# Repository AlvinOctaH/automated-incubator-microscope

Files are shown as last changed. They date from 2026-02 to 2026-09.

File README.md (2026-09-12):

# 🔬 Automated Incubator Microscope

<div align="center">





**A custom 3-axis automated microscope stage for continuous long-term live-cell imaging, developed at NCKU.**

[Overview](#overview) · [Mechanical](#-mechanical) · [Electrical](#-electrical) · [Software](#-software)

</div>

---

## Overview

An automated XYZ microscope stage designed for continuous 24/7 brightfield imaging of biological samples (spheroids) in wellplates. Built around a Raspberry Pi 4 and Arduino Nano V3, the system enables unattended long-term live-cell imaging with motorized focus and sample positioning.

<p align="center">
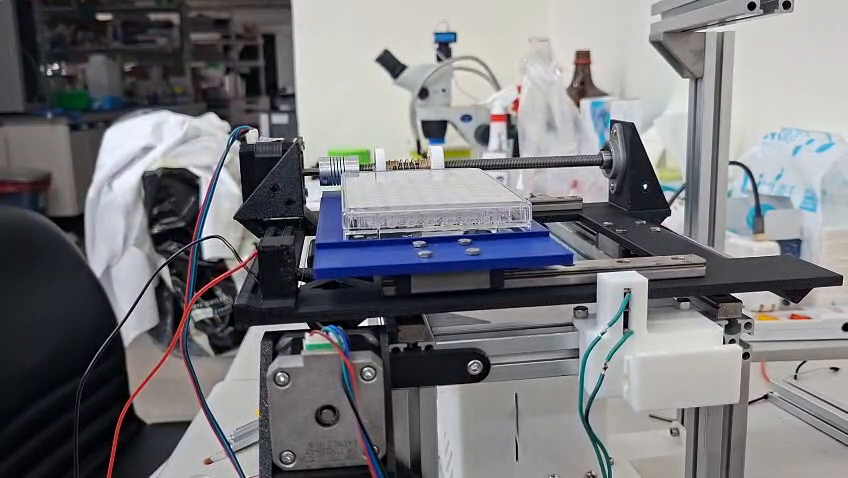
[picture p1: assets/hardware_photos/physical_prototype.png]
  
  <br/><sub>The assembled prototype — wellplate stage, lead screws, and objective column.</sub>
</p>

| Feature | Specification |
| :--- | :--- |
| Axes | X, Y, Z (independent translational) |
| Linear Resolution | 5 µm/step (full-step) |
| Travel (Z) | ~15 mm |
| Motor Driver | DRV8825 |
| Controller | Arduino Nano V3 + Raspberry Pi 4 |
| Camera | Raspberry Pi HQ Camera (IMX477) |
| Target Sample | 96-well plate |
| Primary Material | PLA-CF |
| Operating Mode | Continuous 24/7 |

**Objectives**

- Develop a 3-axis (XYZ) automated microscope stage capable of functioning reliably inside a standard cell culture incubator.
- Enable automated brightfield imaging across all 96 wells in serpentine order with minimal user intervention.
- Minimize contamination risk and preserve spheroid sample integrity throughout continuous long-term experiments.

---

## Related Work

A few existing projects tackle automated or incubator-compatible microscopy:

- Baudin et al., 2021 — [Low cost cloud based remote microscopy for biological sciences](https://doi.org/10.48550/arXiv.2106.07419) (the "Picroscope," a cloud-controlled remote imaging platform for cell culture plates)
- Burke et al., 2024 — [EnderScope: A Low-Cost 3D-Printer-Based Scanning Microscope](https://doi.org/10.1098/rsta.2023.0214)
- Dégut & Plevin, 2025 — [An open-sourced 3D printable microscope with a large CNC stage](https://doi.org/10.3390/mi13060833)
- Gervasi et al., 2022 — [Automated Open-Hardware Multiwell Imaging Station for Microorganisms Observation](https://doi.org/10.1101/2024.12.31.630915)
- Merces et al., 2021 — [The incubot: A 3D printer-based microscope for long-term live cell imaging within a tissue culture incubator](https://doi.org/10.1016/j.ohx.2021.e00189)

This project's own angle: a stage sized and optically configured specifically for a standard 96-well plate, with a quantified per-axis repeatability test (not just a claim that it's repeatable) and a web-based experiment runner built for unattended multi-day scans.

---

## 🔩 Mechanical

### 1. Components & Specs
| Component | Specification | Quantity |
| :--- | :--- | :---: |
| Stepper Motor | NEMA17 42-40, 1.8°/step, ~40 N·cm holding torque | 3 |
| Lead Screw | T8, 1 mm pitch | 3 |
| Anti-backlash Nut | 8 mm | 3 |
| Flexible Coupler | 5 mm to 8 mm | 3 |
| Linear Rail | MGN12H | 3 |
| Aluminum Extrusion | Alpro, various lengths | — |

#### Enclosure (design only — not yet fabricated)

<p align="center">
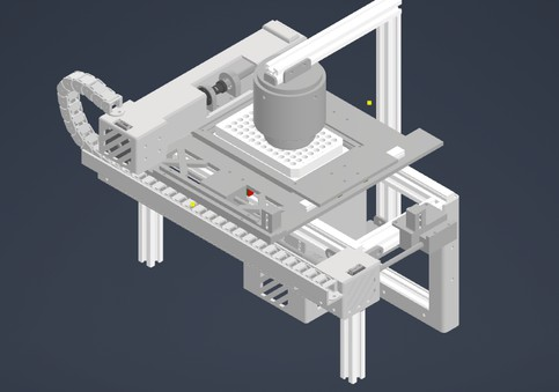
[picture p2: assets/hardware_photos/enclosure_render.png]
  
</p>

> This protective enclosure has been designed in CAD but not yet 3D-printed or fitted to the prototype — it's not part of the assembled hardware shown elsewhere in this README.

### 2. Motion Calculation

#### Degrees of Freedom (DOF)

<p align="center">
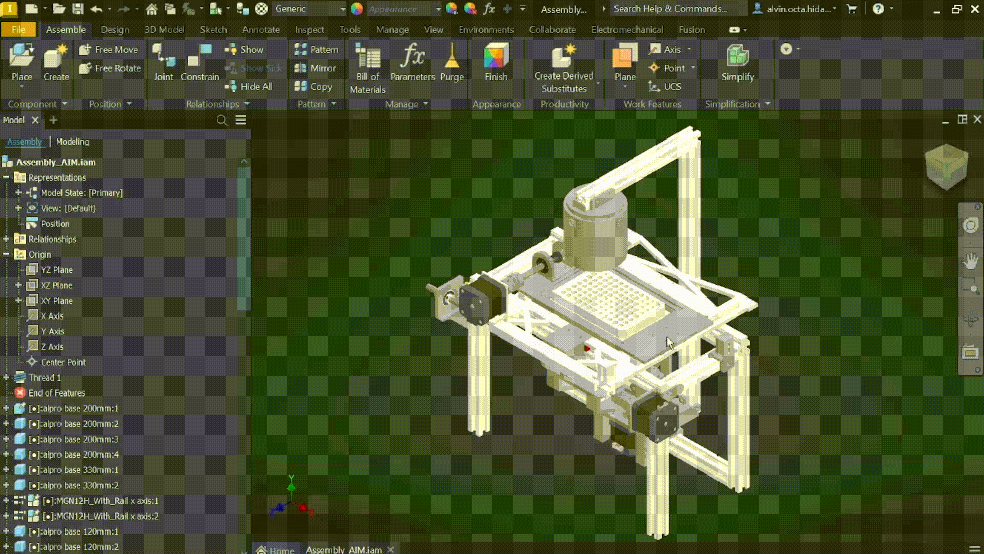
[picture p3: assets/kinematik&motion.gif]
  
</p>

Each axis provides exactly 1 translational DOF with no unintended rotational or parasitic motion, confirming proper constraint and assembly.

| Axis | DOF Type | Notes |
| :--- | :--- | :--- |
| X | 1 Translational | Stacked system |
| Y | 1 Translational | — |
| Z | 1 Translational | Focus axis |

#### Lead Screw Motion

- **Lead screw pitch:** 1 mm/rev  
- **Stepper motor:** 200 steps/rev, full-step (all axes)

**Theoretical linear resolution:**

$$
\text{Resolution} = \frac{\text{Lead Screw Pitch}}{\text{Steps per Revolution}} = \frac{1\ \text{mm}}{200 \times 1} = 0.005\ \text{mm} = 5\ \mu\text{m}
$$

**Required steps for full Z travel (9 mm gap between plates):**

$$
\text{Required Steps} = \frac{9\ \text{mm}}{5\ \mu\text{m}} = \frac{9000\ \mu\text{m}}{5\ \mu\text{m}} = 1800\ \text{steps}
$$

#### Interference Analysis

<p align="center">
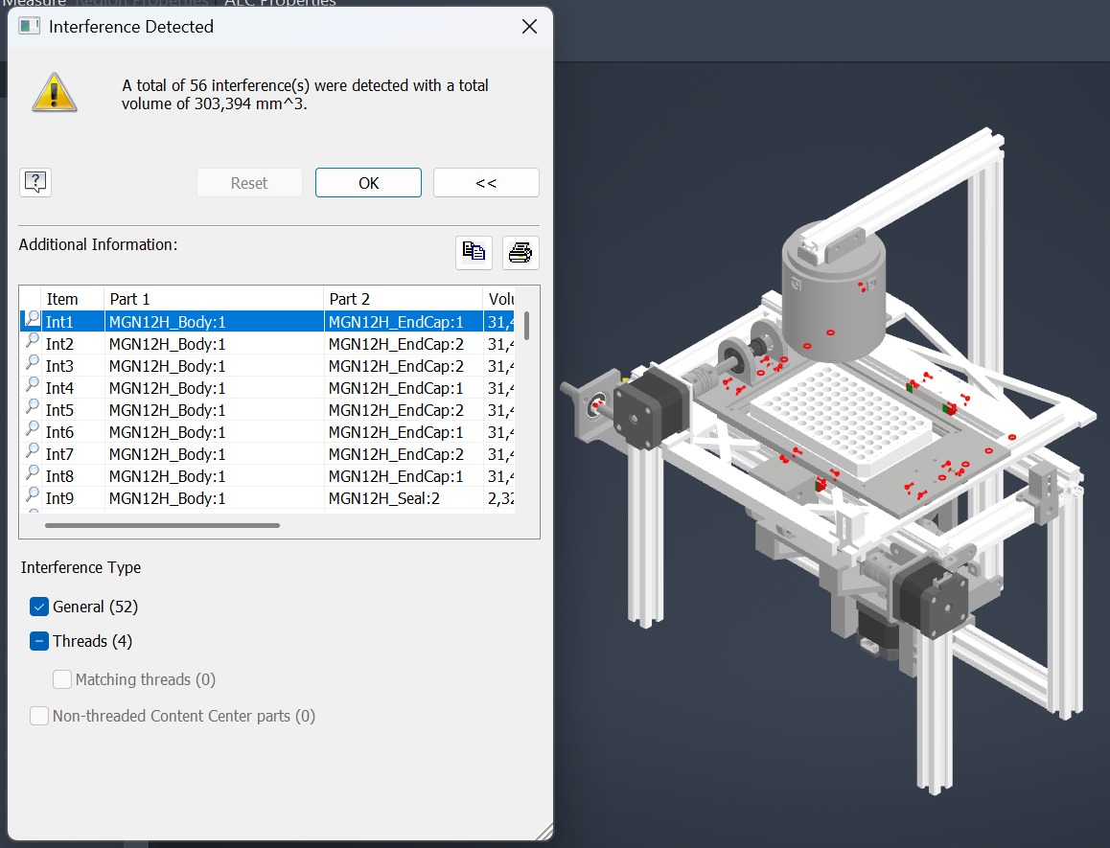
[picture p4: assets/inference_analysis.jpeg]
  
</p>

> ⚠️ **Note:** The interference analysis flags several overlaps in the CAD model. These occur within intentionally modeled precision components (linear rails, KFL08 bearing threaded regions) and are not physically relevant in real-world assembly. No functional collisions exist in the final design.

---

### 3. Material Comparison

Static load analysis was performed on the stage plate under gravity only
(−Z, 9.81 m/s²). Three materials were evaluated: **PLA-CF**, **PLA-Basic**,
and **Aluminum 6061**.

**Displacement** shows how much the structure physically deforms under load —
lower values indicate a stiffer, more stable platform, which is critical for
maintaining focus consistency during imaging.

**Von Mises Stress** shows the internal stress distribution across the
structure. Results dominated by blue contour across all three materials
indicate that stress levels remain well within safe limits throughout the
structural body under gravity-only loading.

**Safety Factor** is derived from the ratio of material yield strength to
local von Mises stress. Values above 2 are generally considered acceptable
in engineering practice. The minimum value is read from the Inventor SF
contour plot — peak stress occurs only at localized concentration points,
while the majority of the structure maintains a high safety margin as
confirmed by the blue-dominated contour.

> ⚠️ Note: Peak displacement values include contribution from motor assembly
> motion. Structural frame comparison is best assessed from the color contour
> distribution in the images above.

#### Material Properties

| Property | PLA-CF | PLA-Basic | Aluminum 6061 |
| :--- | :---: | :---: | :---: |
| Young Modulus (MPa) | 2790 | 2750 | Default Autodesk Inventor |
| Poisson Ratio | 0.33 | 0.36 | Default Autodesk Inventor |
| Shear Modulus (MPa) | 1048 | 1010 | Default Autodesk Inventor |
| Yield Strength (MPa) | 38 | 35 | Default Autodesk Inventor |

#### A. PLA-CF

<details>
<summary>Displacement</summary>
<p align="center">
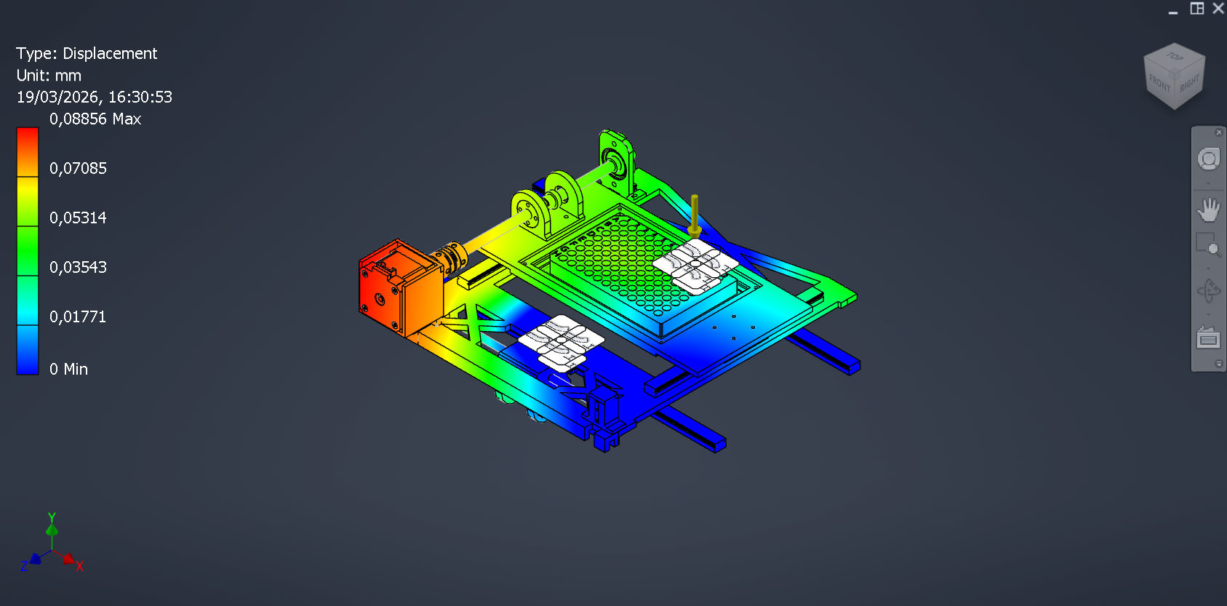
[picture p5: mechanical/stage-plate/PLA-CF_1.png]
  
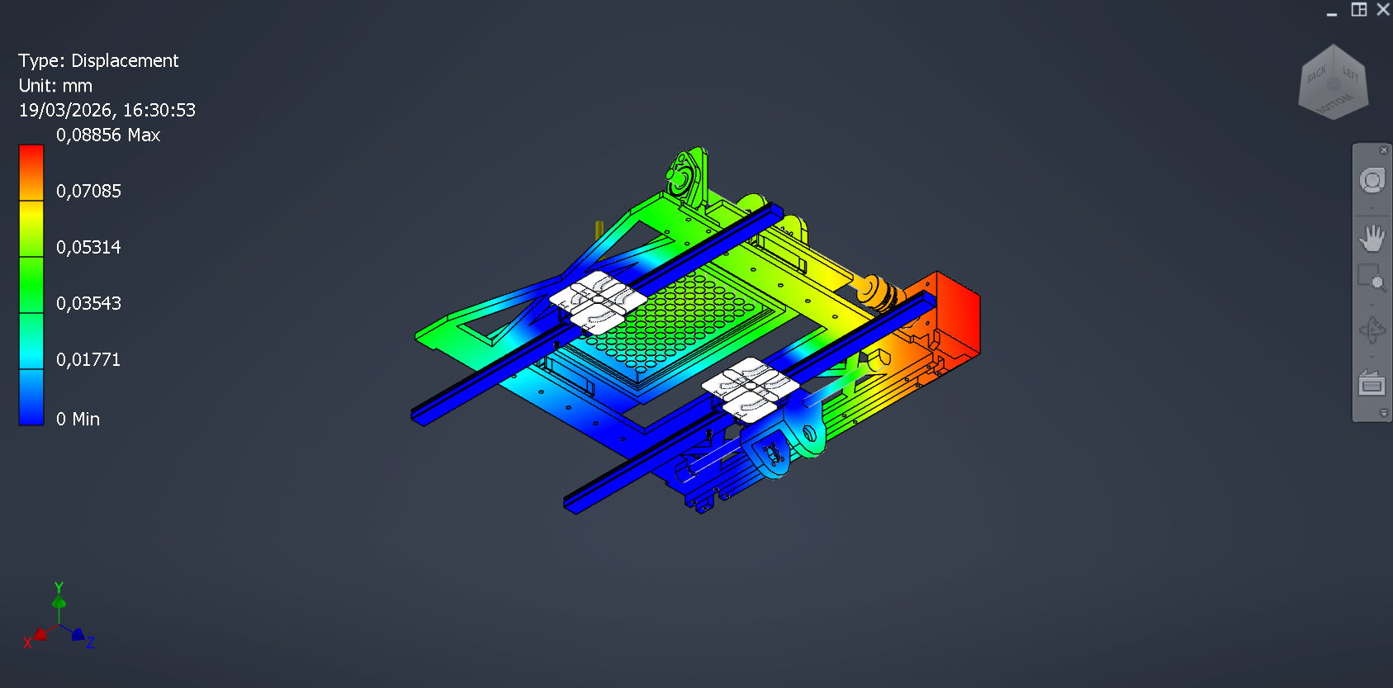
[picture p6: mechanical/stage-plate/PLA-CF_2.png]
  
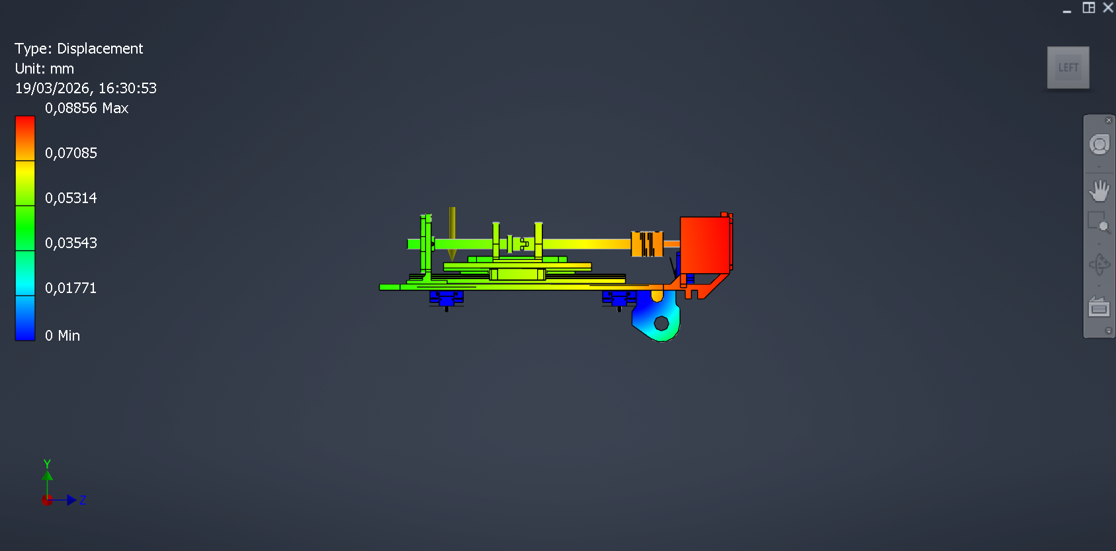
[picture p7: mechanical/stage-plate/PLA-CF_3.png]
  
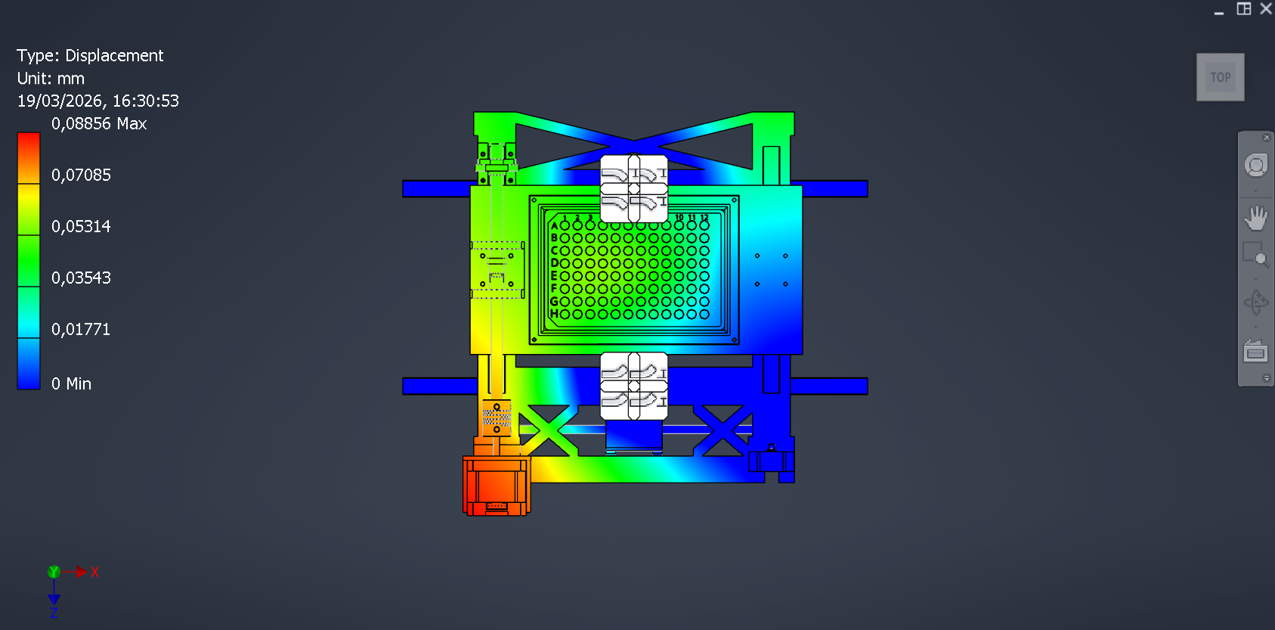
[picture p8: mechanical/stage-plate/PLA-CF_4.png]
  
</p>
</details>

<details>
<summary>Von Mises Stress</summary>
<p align="center">
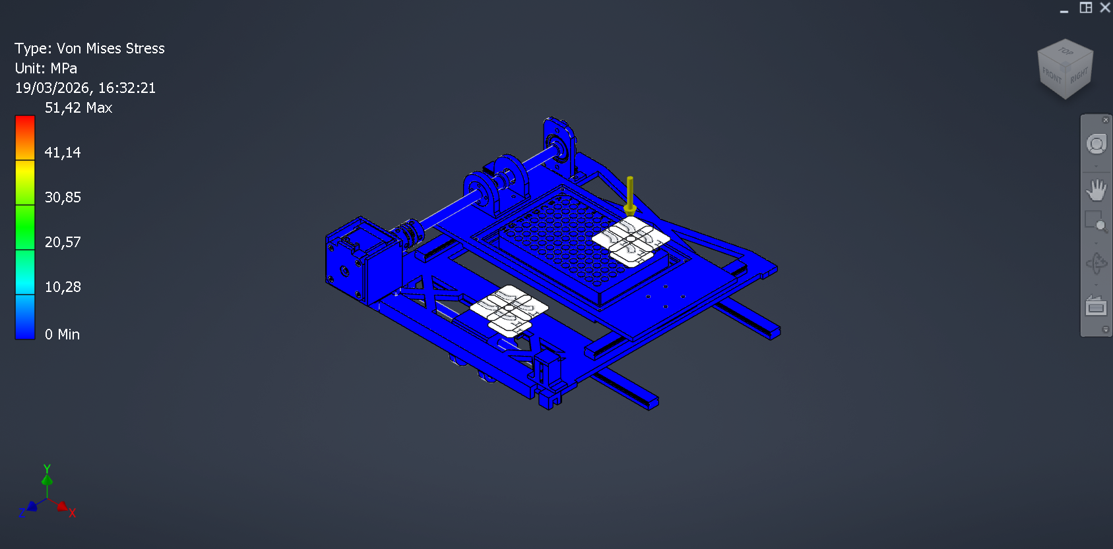
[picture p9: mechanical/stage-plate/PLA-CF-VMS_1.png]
  
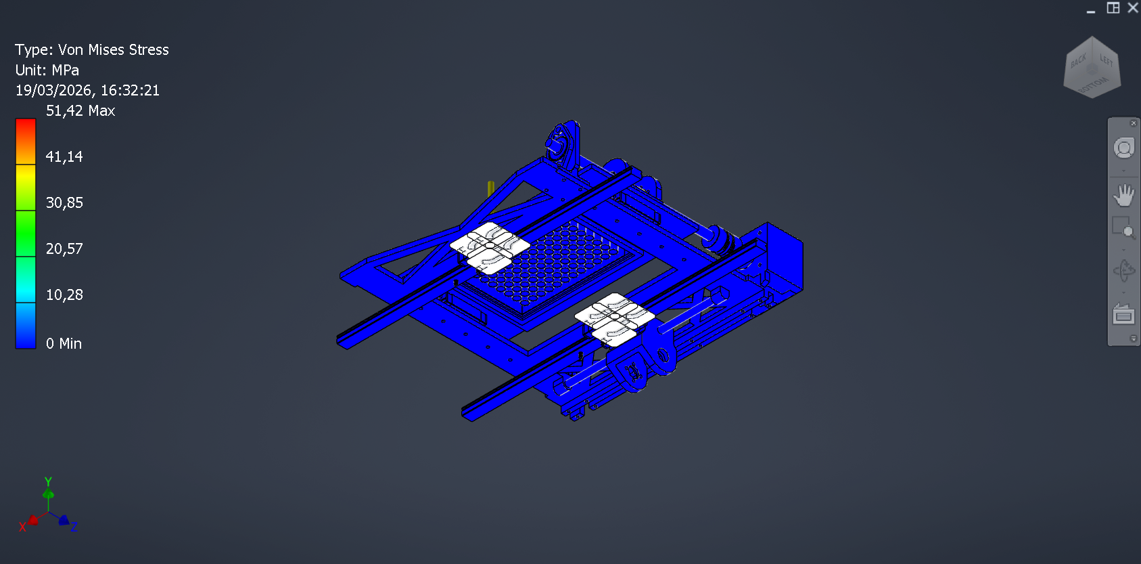
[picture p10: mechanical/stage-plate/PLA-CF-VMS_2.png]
  
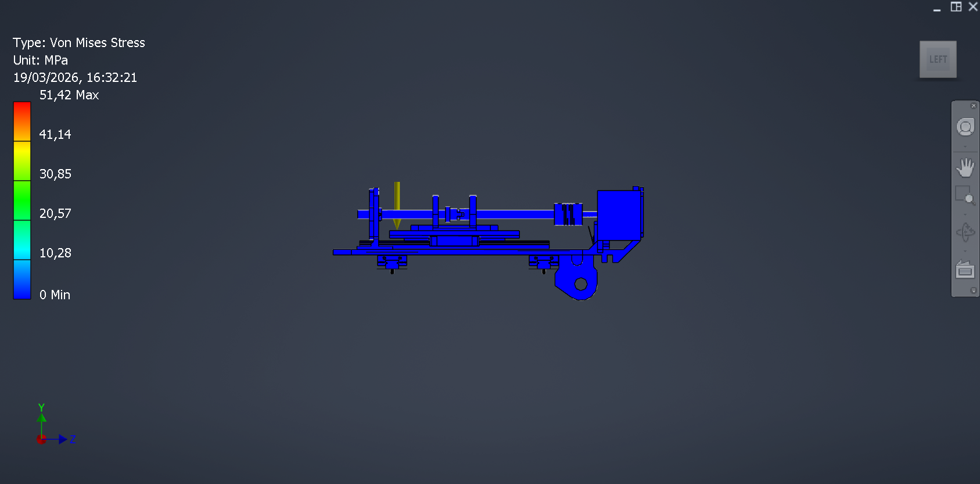
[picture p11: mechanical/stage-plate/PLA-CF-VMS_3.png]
  
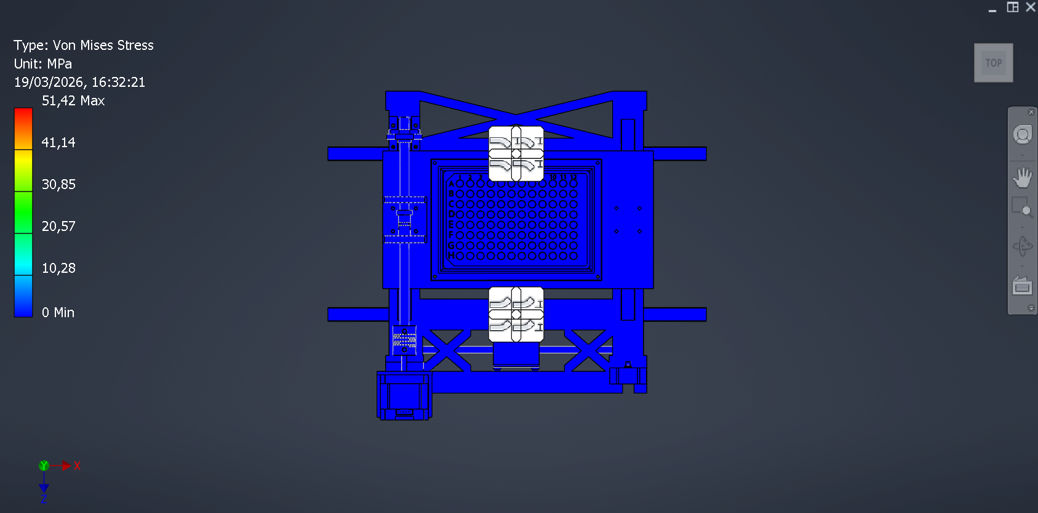
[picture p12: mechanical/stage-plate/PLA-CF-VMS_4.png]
  
</p>
</details>

<details>
<summary>Safety Factor</summary>
<p align="center">
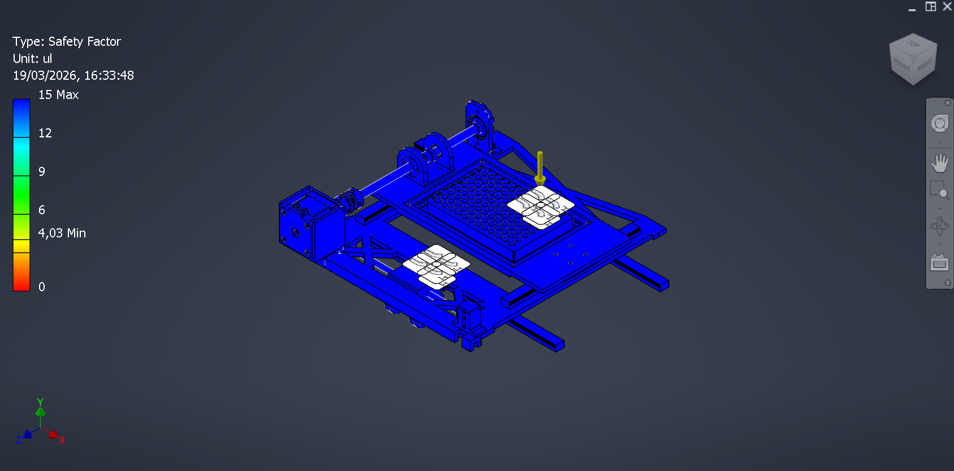
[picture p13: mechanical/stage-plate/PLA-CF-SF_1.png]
  
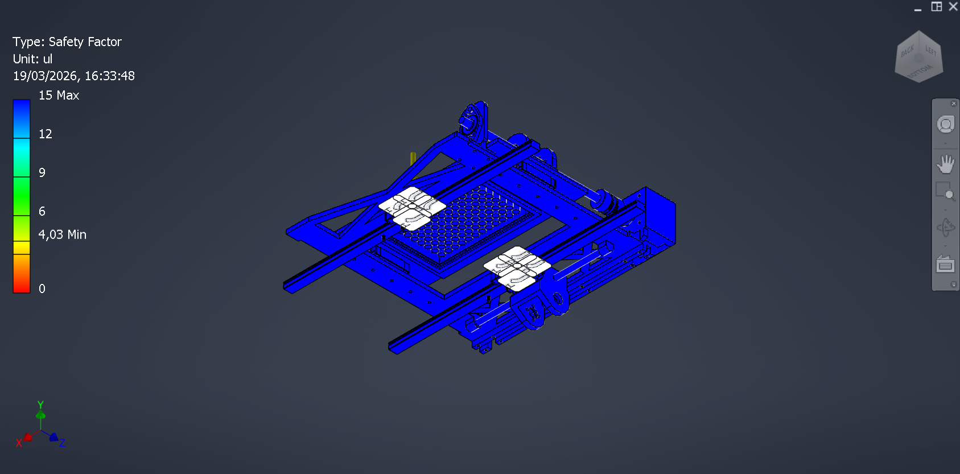
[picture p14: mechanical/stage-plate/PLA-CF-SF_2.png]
  
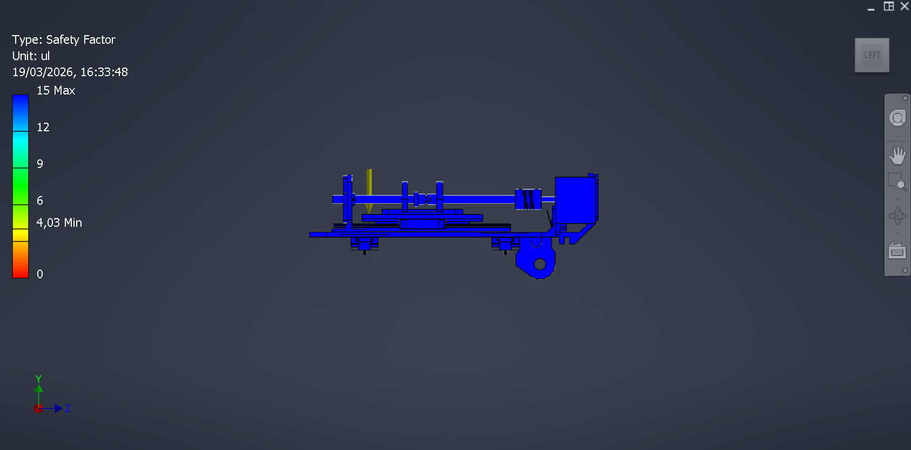
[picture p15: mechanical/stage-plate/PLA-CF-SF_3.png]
  
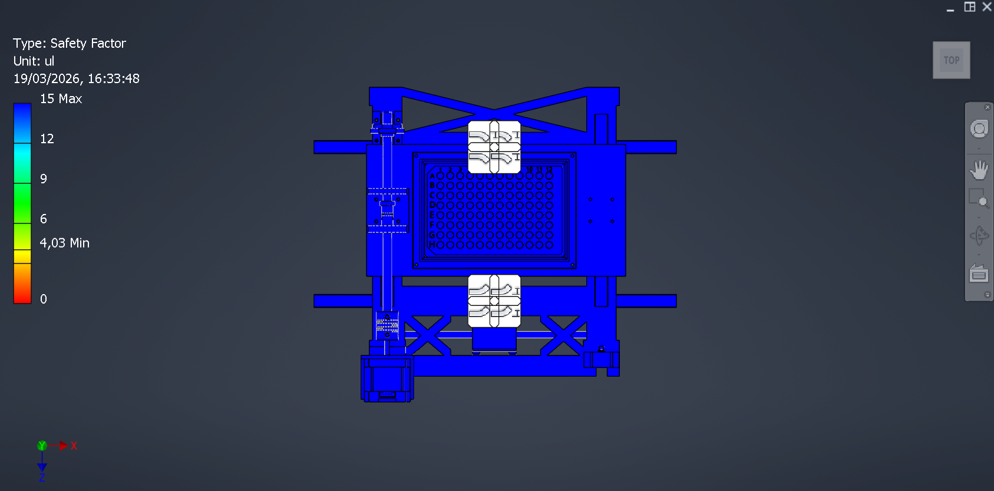
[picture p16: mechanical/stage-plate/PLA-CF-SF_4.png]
  
</p>
</details>

- Max displacement: **0.089 mm**
- Max von Mises stress: **51.42 MPa** — stress distribution dominated by blue contour, structure is safe throughout
- Min safety factor: **4.03** — well above acceptable threshold
- Carbon fiber reinforcement improves stiffness compared to PLA-Basic

#### B. PLA-Basic

<details>
<summary>Displacement</summary>
<p align="center">
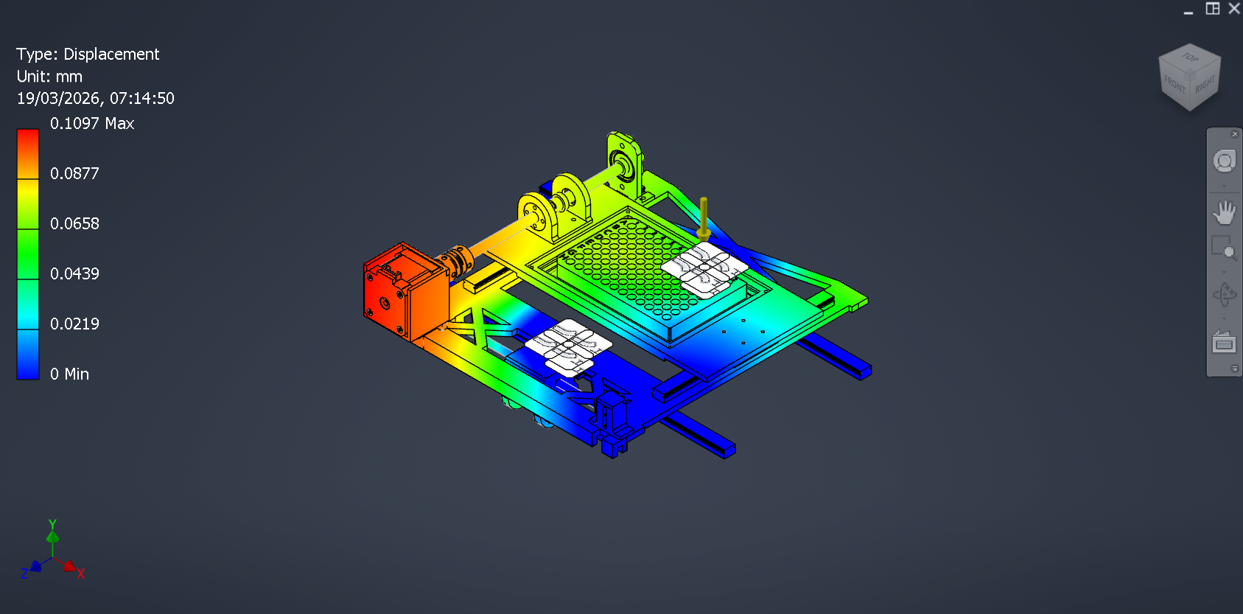
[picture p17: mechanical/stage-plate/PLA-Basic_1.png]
  
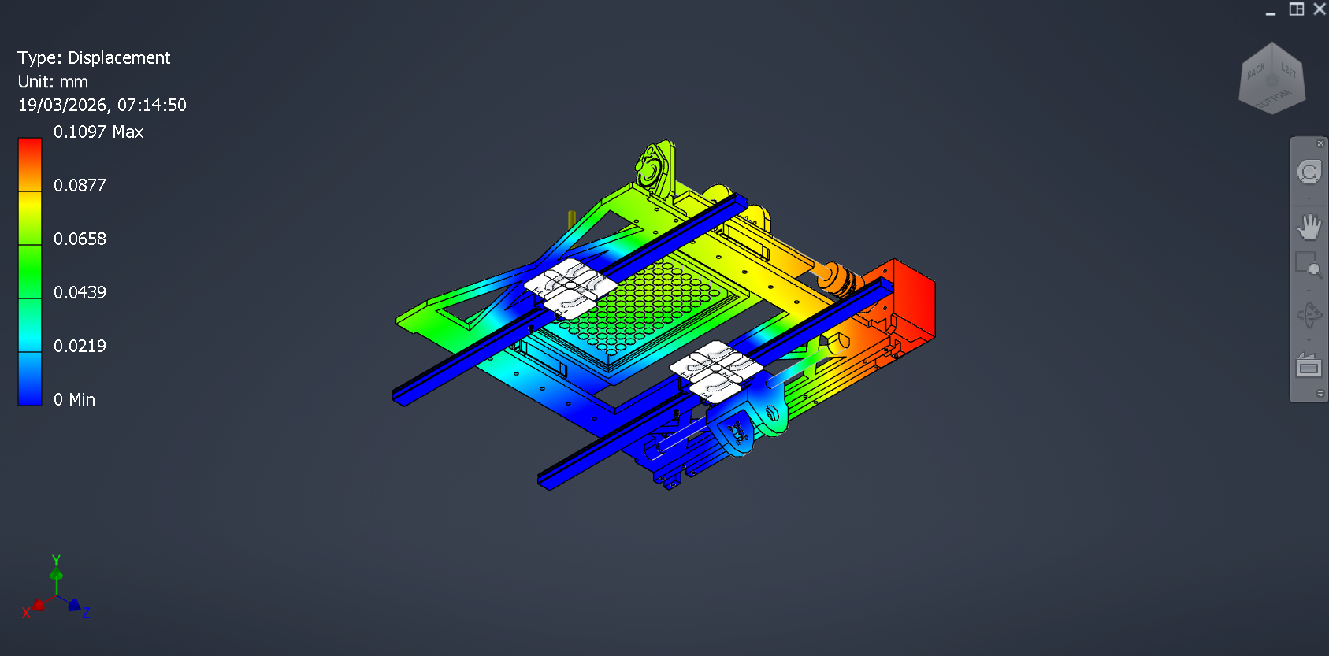
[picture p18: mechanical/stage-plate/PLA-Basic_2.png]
  
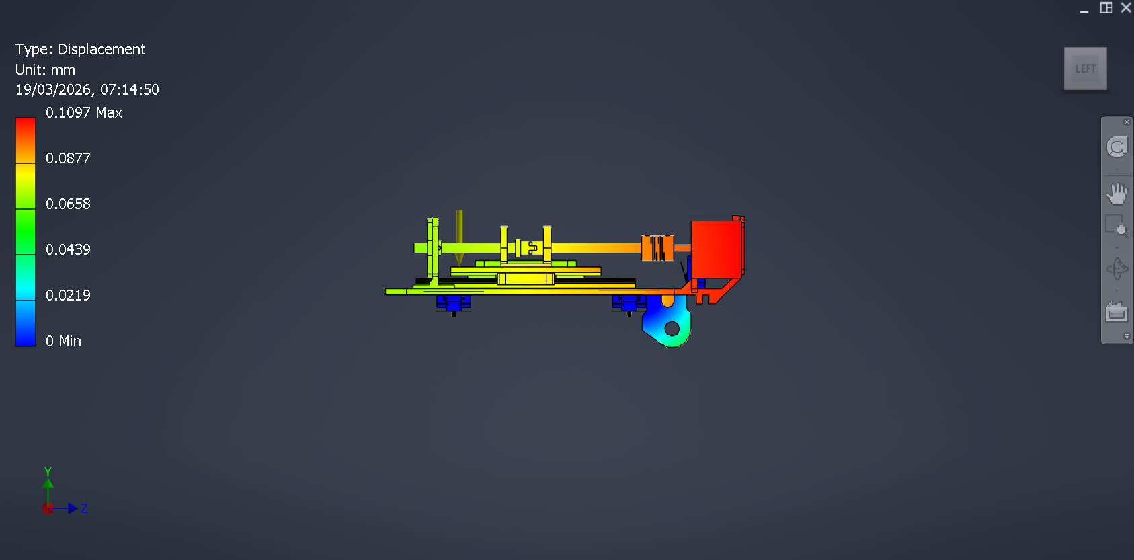
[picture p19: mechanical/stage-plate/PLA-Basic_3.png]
  
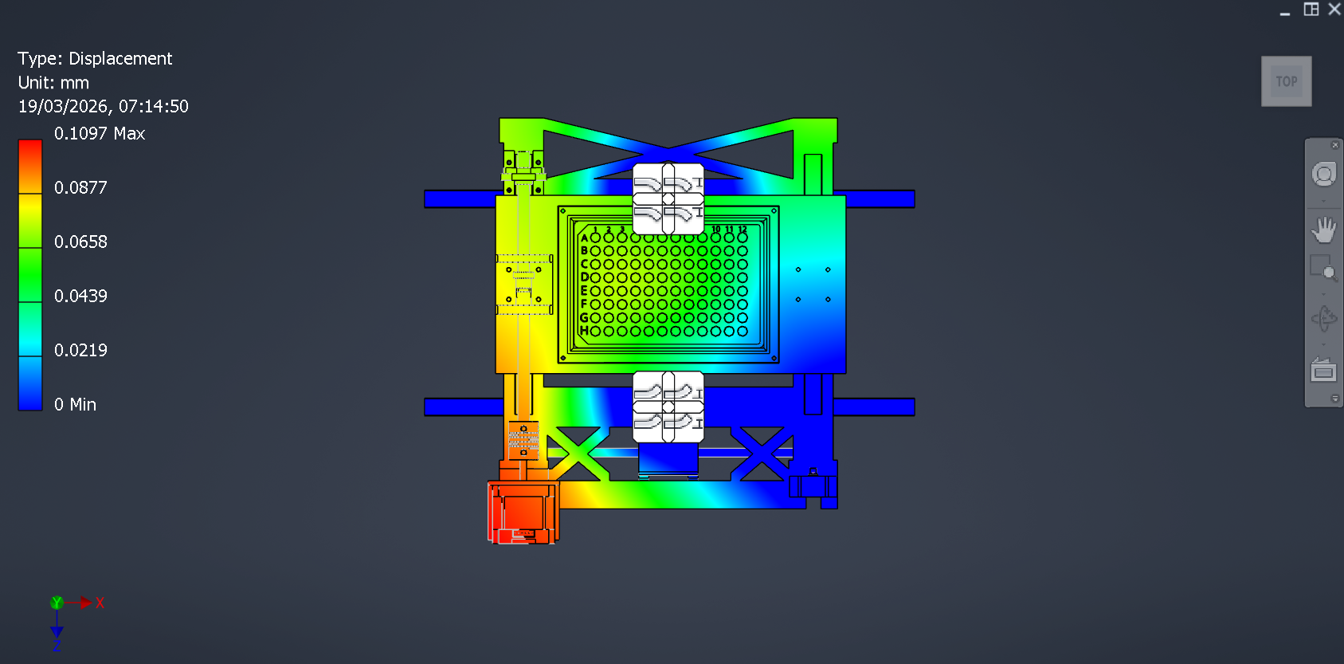
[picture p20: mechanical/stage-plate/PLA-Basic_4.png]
  
</p>
</details>

<details>
<summary>Von Mises Stress</summary>
<p align="center">
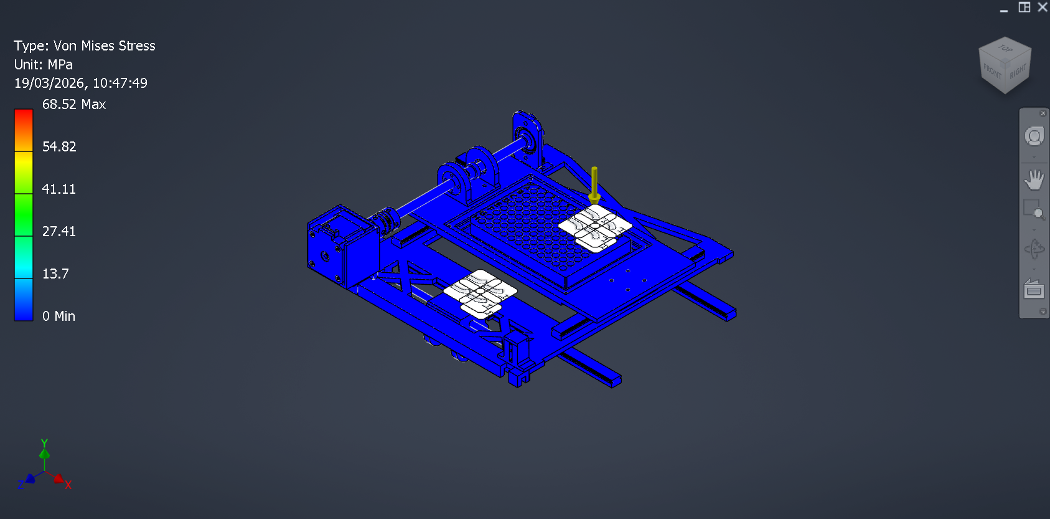
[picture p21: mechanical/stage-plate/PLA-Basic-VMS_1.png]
  
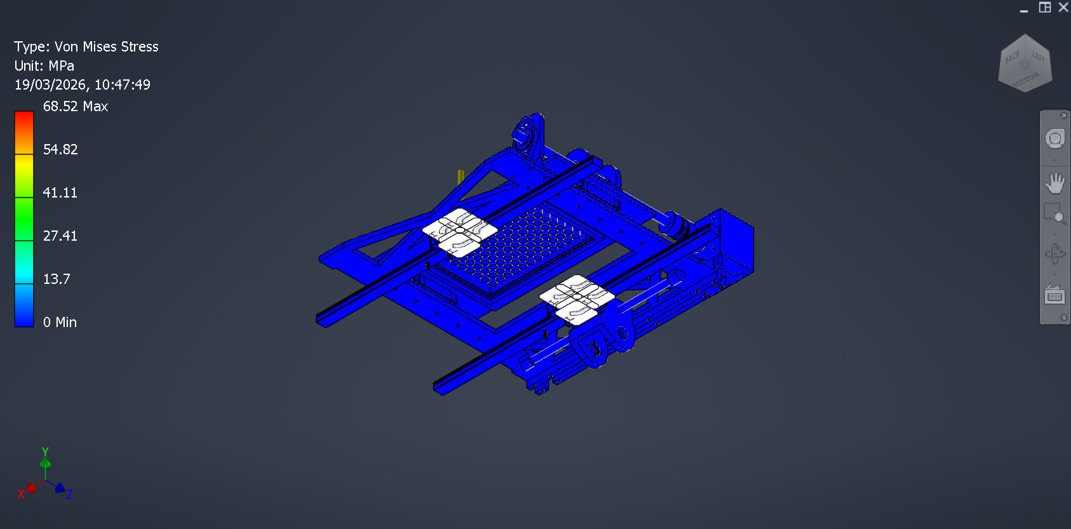
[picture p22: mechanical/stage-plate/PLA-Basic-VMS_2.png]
  
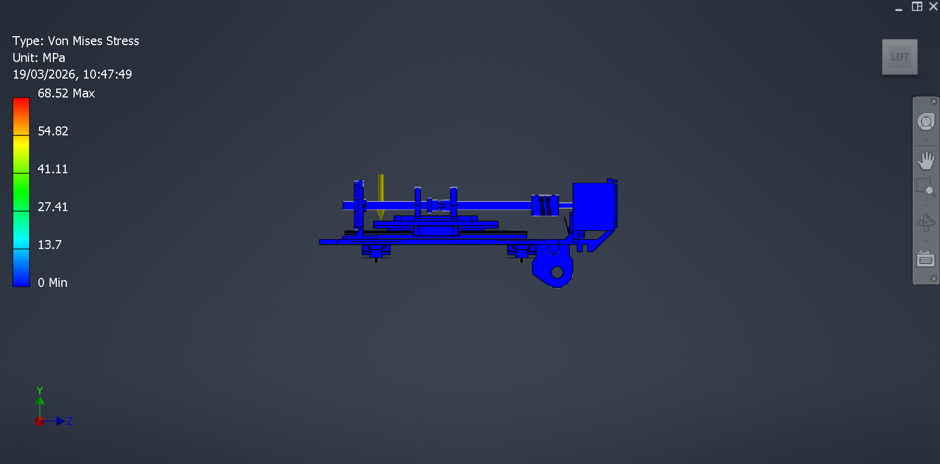
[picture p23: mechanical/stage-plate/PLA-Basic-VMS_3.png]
  
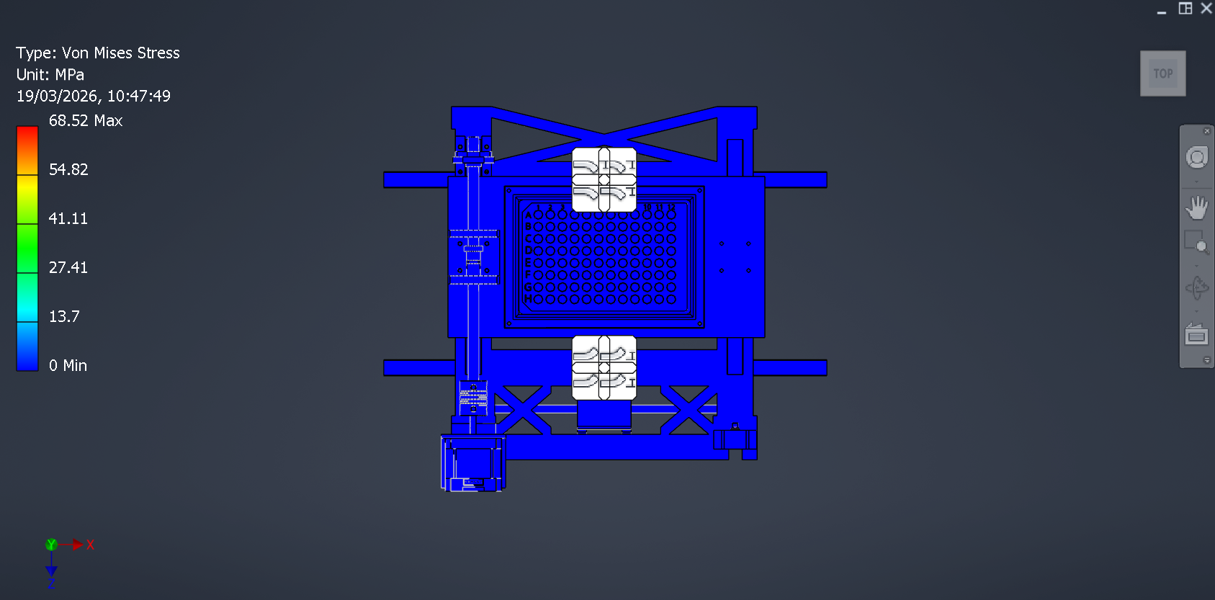
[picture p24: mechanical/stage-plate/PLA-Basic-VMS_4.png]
  
</p>
</details>

<details>
<summary>Safety Factor</summary>
<p align="center">
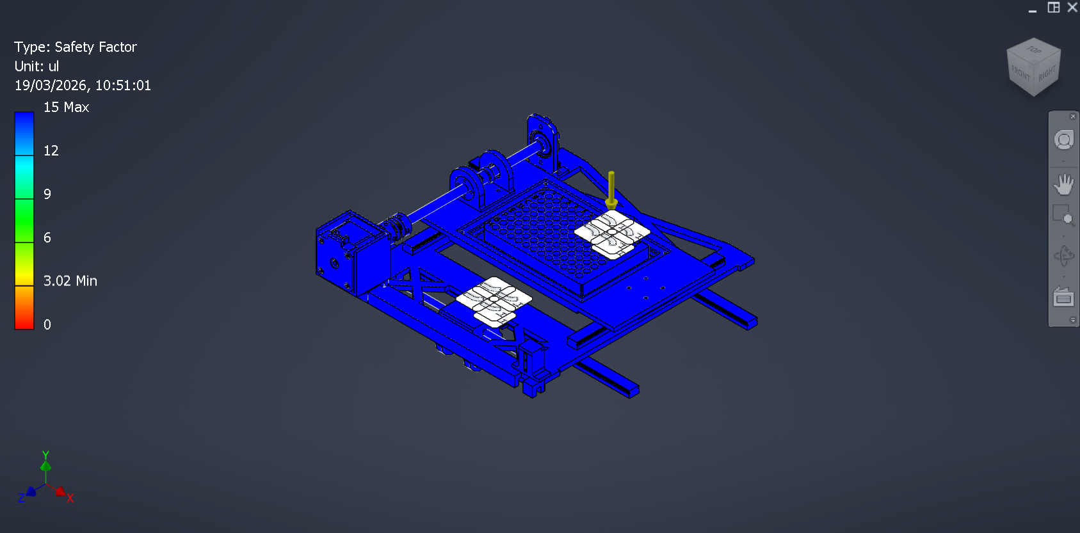
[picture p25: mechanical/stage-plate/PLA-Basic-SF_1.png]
  
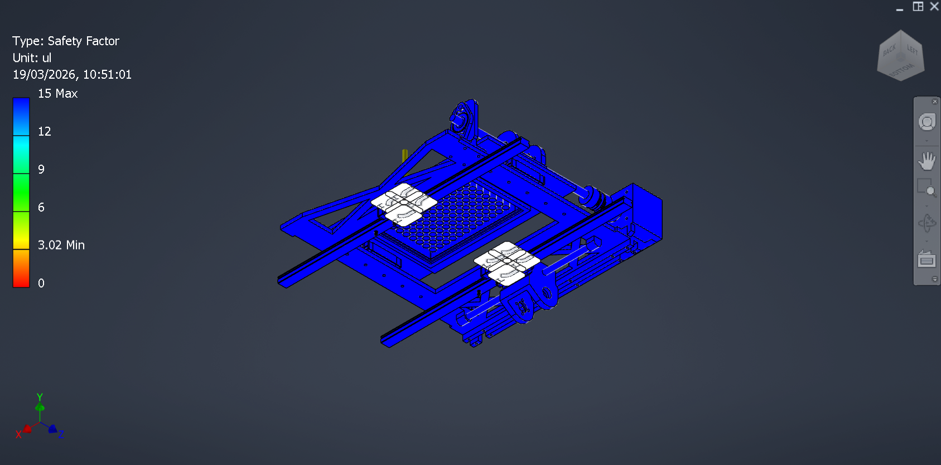
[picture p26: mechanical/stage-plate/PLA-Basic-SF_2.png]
  
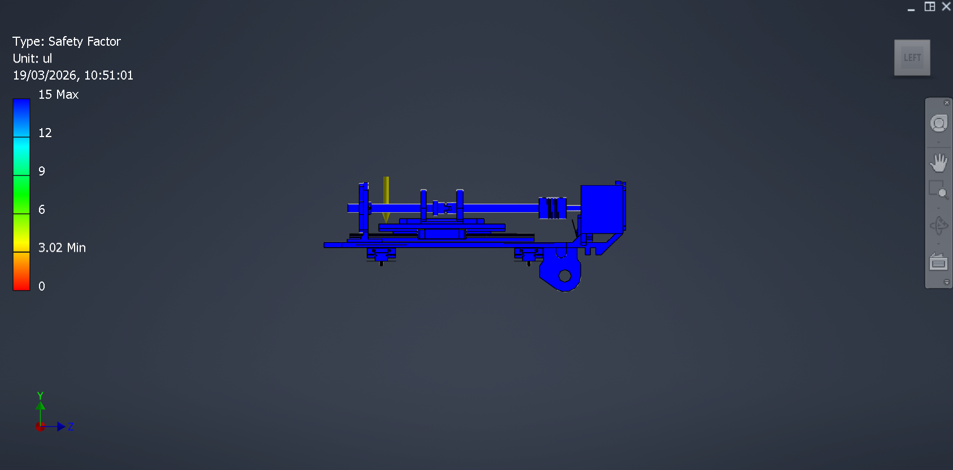
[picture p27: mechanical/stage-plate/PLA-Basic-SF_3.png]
  
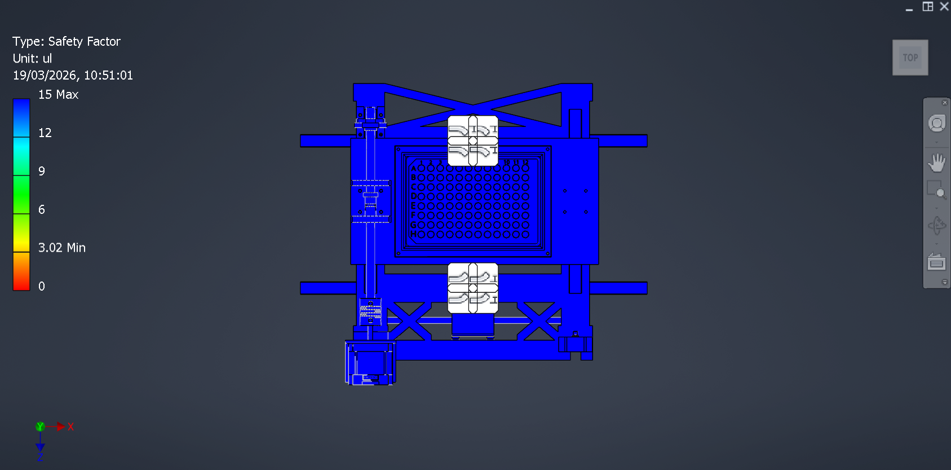
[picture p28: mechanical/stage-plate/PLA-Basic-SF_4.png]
  
</p>
</details>

- Max displacement: **0.11 mm** — highest among all three materials
- Max von Mises stress: **68.52 MPa** — stress distribution dominated by blue contour, structure is safe throughout
- Min safety factor: **3.02** — above acceptable threshold but lowest among three materials
- Higher deformation due to absence of carbon fiber reinforcement

#### C. Aluminum 6061

<details>
<summary>Displacement</summary>
<p align="center">
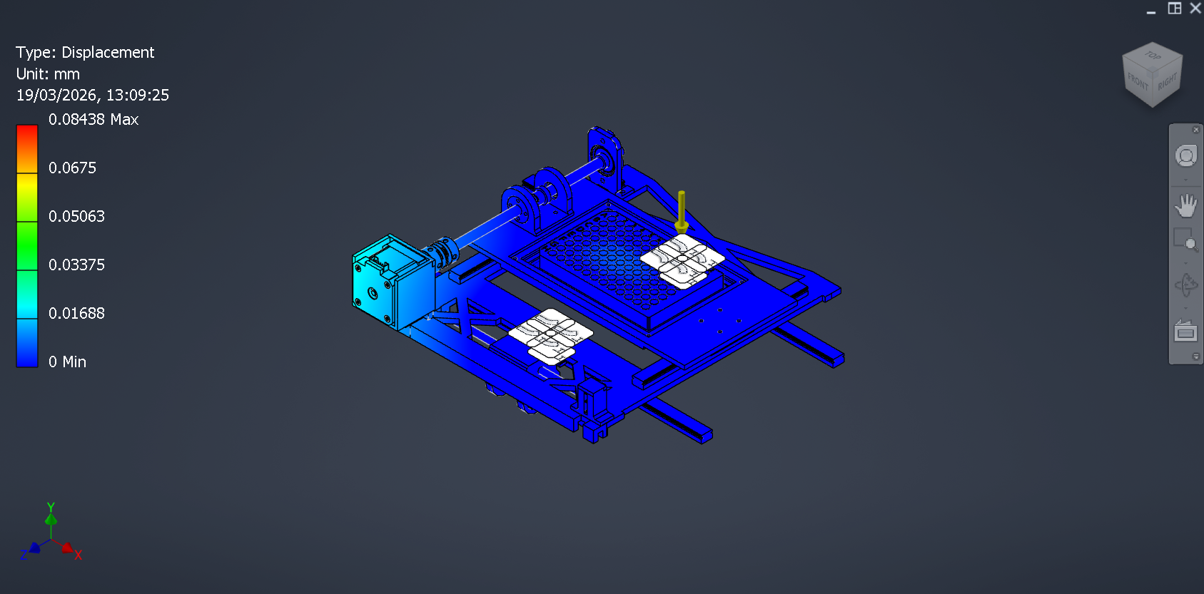
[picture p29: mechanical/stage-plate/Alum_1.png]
  
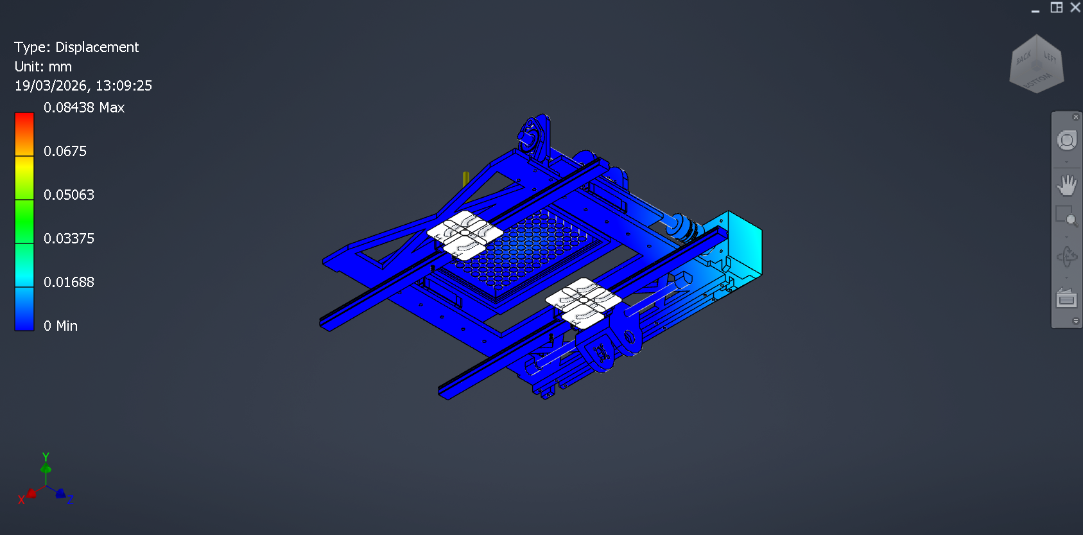
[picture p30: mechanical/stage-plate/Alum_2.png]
  
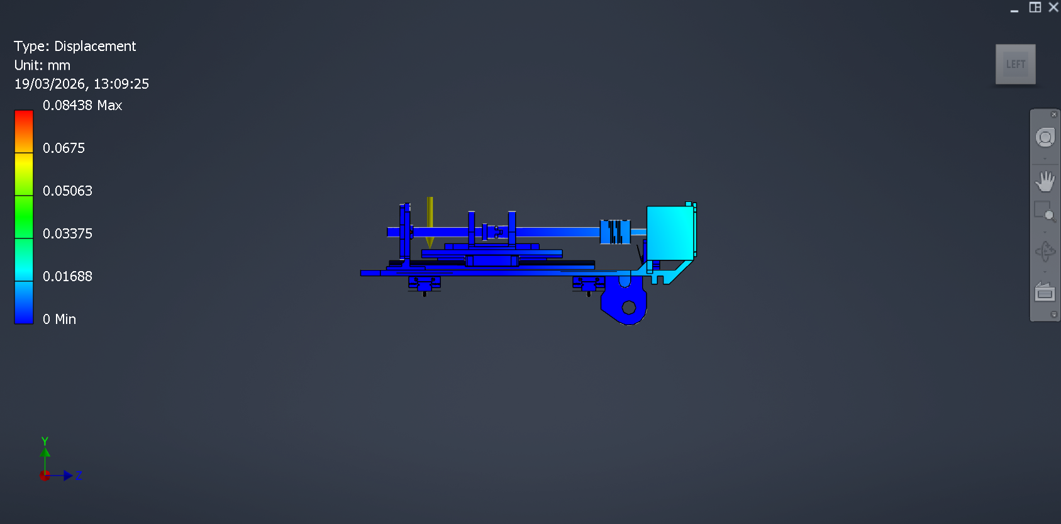
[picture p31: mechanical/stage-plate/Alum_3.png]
  
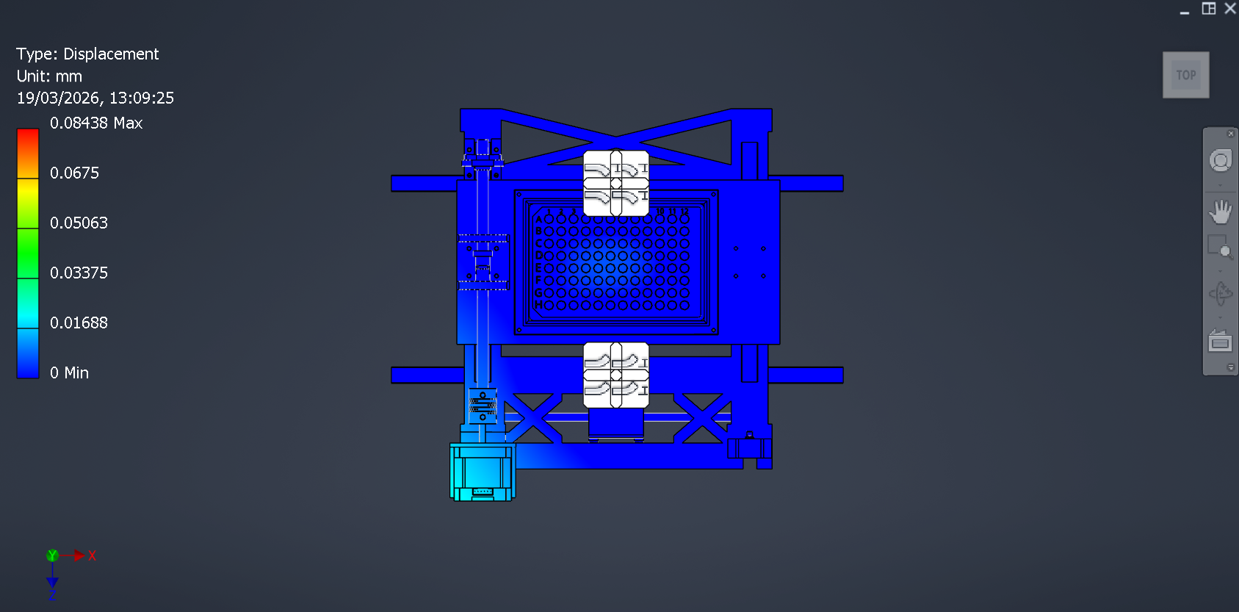
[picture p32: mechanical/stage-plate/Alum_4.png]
  
</p>
</details>

<details>
<summary>Von Mises Stress</summary>
<p align="center">
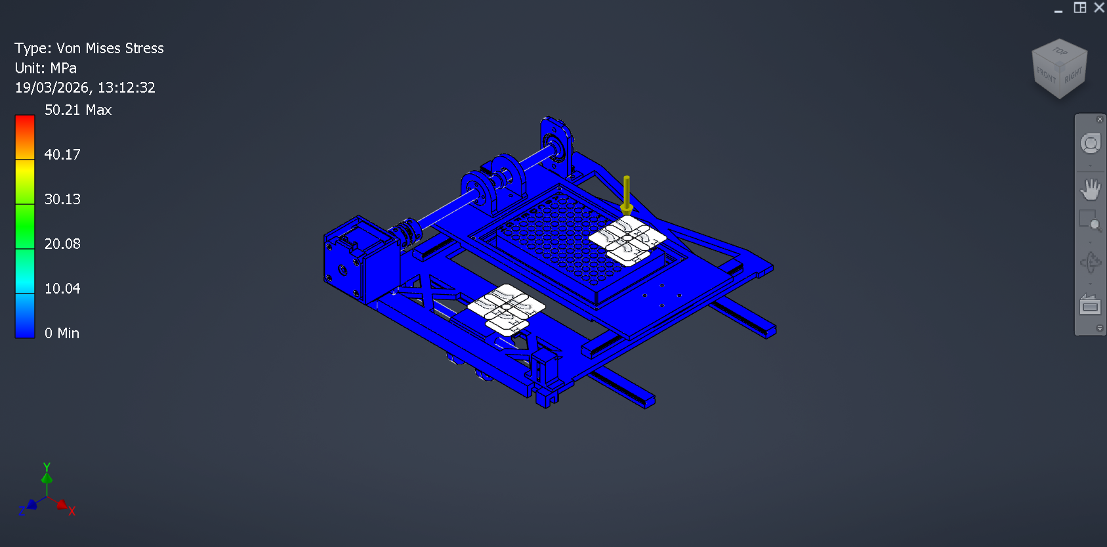
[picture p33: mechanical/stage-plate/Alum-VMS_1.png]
  
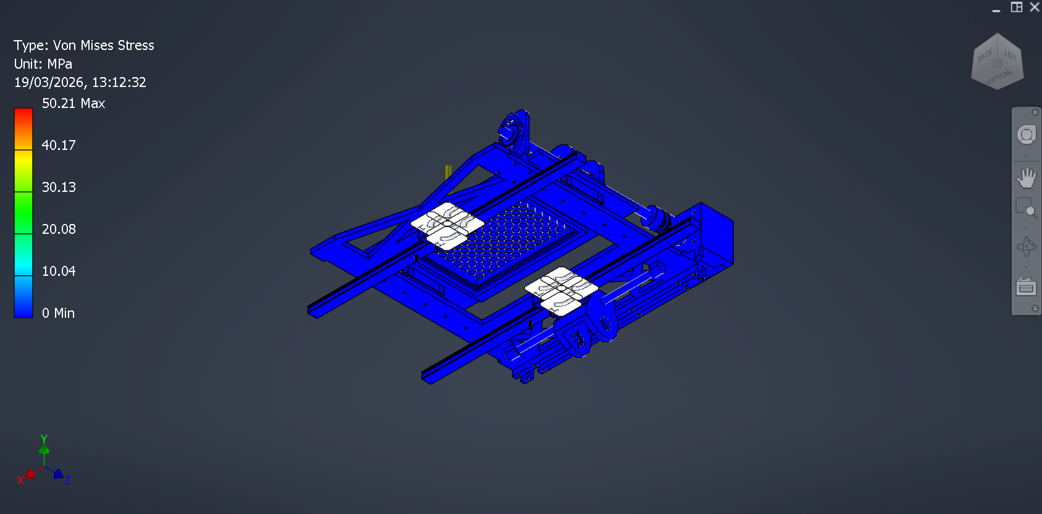
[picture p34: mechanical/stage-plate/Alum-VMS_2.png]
  
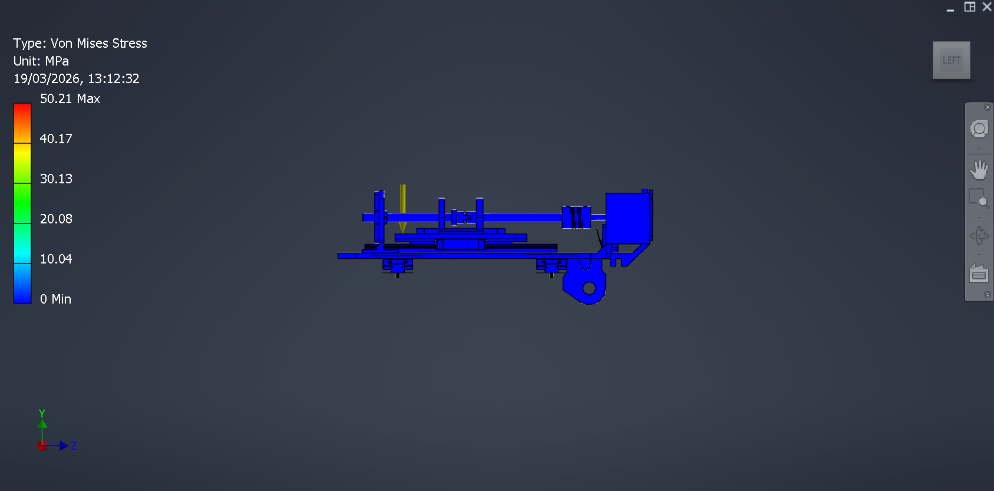
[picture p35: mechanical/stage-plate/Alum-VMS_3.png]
  
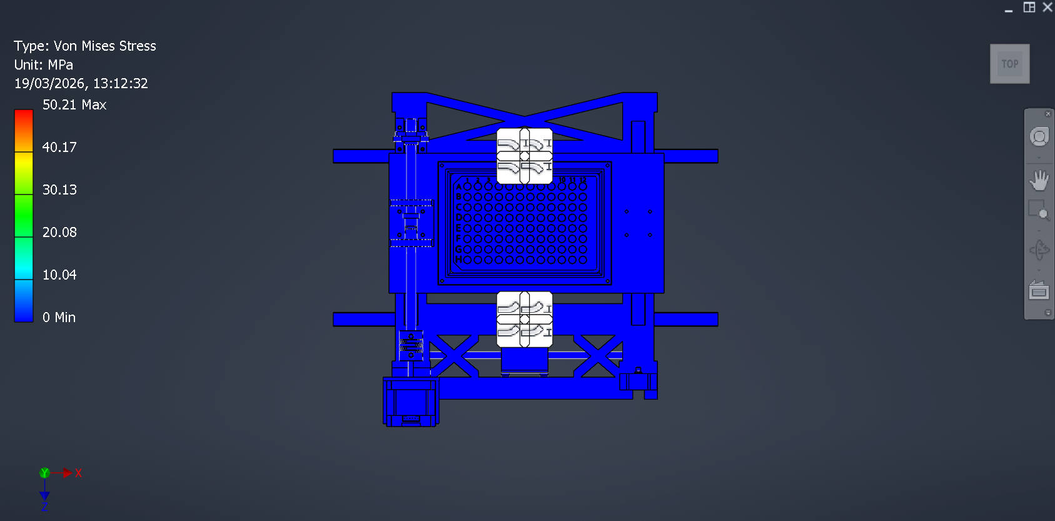
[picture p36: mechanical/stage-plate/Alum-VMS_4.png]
  
</p>
</details>

<details>
<summary>Safety Factor</summary>
<p align="center">
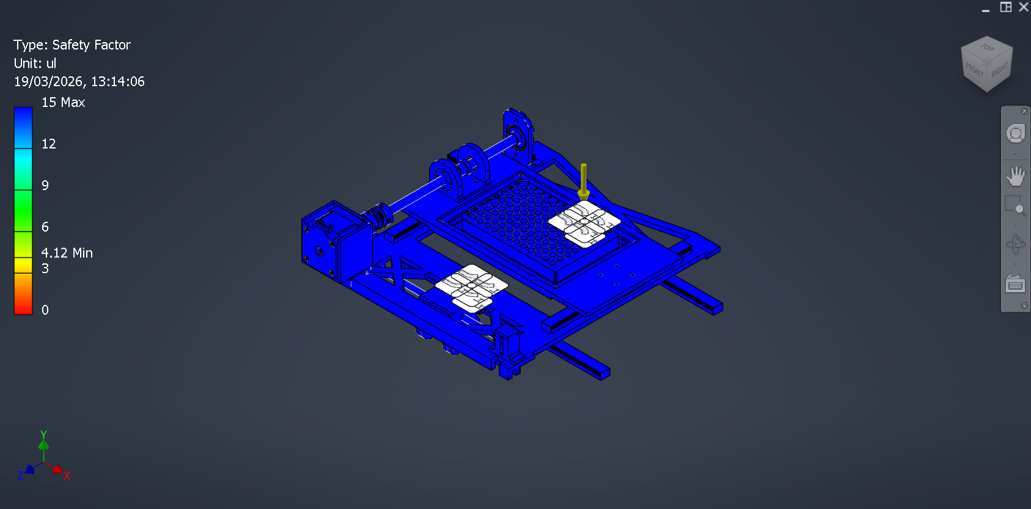
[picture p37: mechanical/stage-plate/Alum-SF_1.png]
  
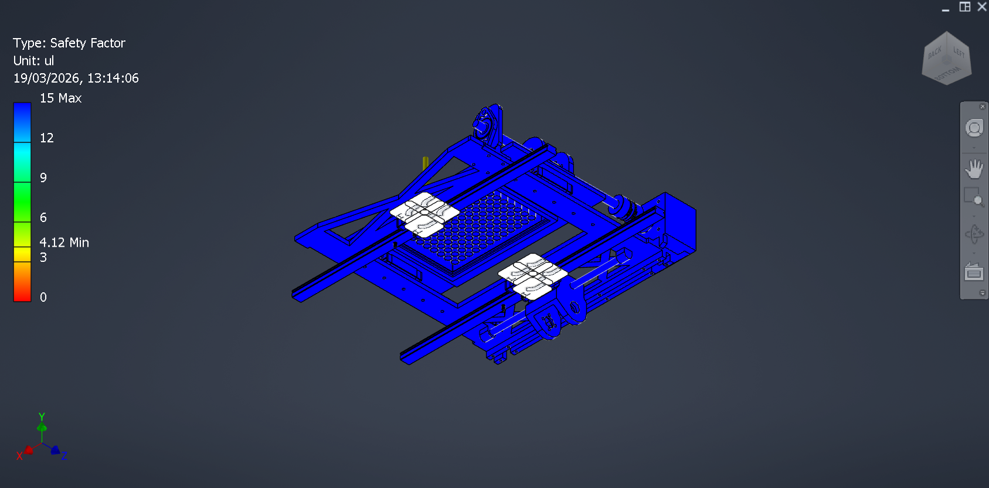
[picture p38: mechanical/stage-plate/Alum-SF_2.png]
  
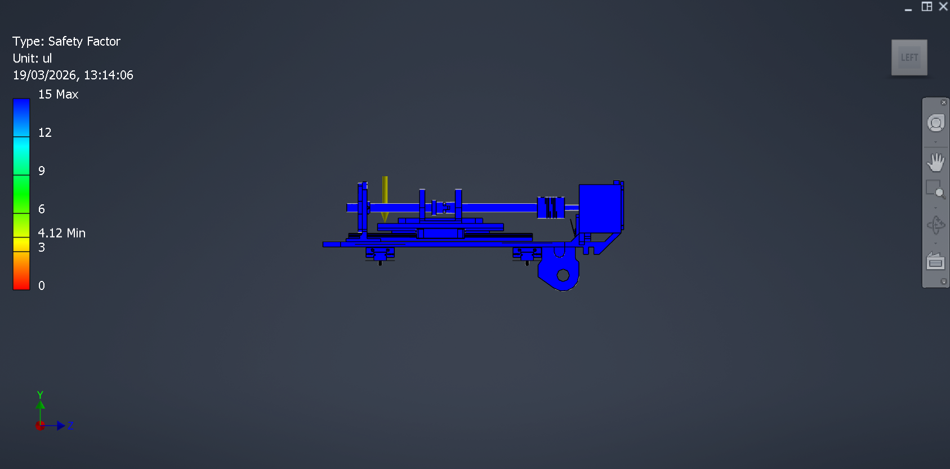
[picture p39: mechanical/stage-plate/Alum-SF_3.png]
  
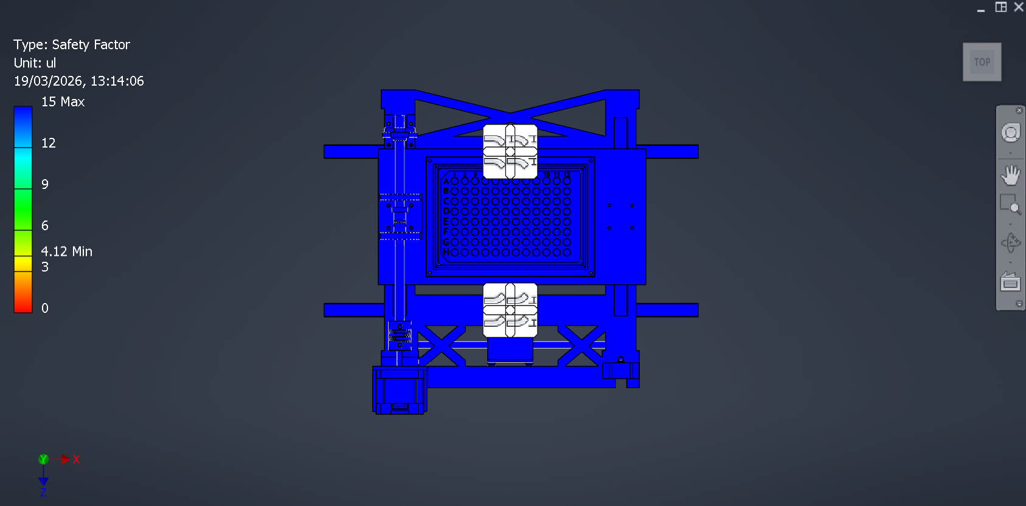
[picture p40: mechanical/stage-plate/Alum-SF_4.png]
  
</p>
</details>

- Max displacement: **~0.017 mm** — lowest among all three materials
- Max von Mises stress: **50.21 MPa** — stress distribution dominated by blue contour, structure is safe throughout
- Min safety factor: **4.12** — highest among three materials
- Negligible deformation under gravity-only loading

#### Comparison Summary

<div align="center">

| Parameter | PLA-Basic | PLA-CF | Aluminum 6061 |
| :--- | :---: | :---: | :---: |
| Max Displacement | 0.11 mm | 0.089 mm | ~0.017 mm |
| Max Von Mises Stress | 68.52 MPa | 51.42 MPa | 50.21 MPa |
| Min Safety Factor | 3.02 | 4.03 | 4.12 |
| Stress Distribution | ✅ Safe (blue) | ✅ Safe (blue) | ✅ Safe (blue) |
| Stiffness | Low | Moderate | Very High |
| Cost | Low | Medium | High |
| Printability | ✅ Easy | ✅ Easy | ❌ Requires machining |
| Verdict | ⚠️ Acceptable | ✅ Selected | Reference only |

</div>

#### Insight

All three materials show safe stress distribution under gravity-only loading, with minimum safety factors well above 2 across the entire structure. Aluminum 6061 offers the best mechanical performance — lowest displacement (~0.017 mm) and highest safety factor (4.12) — but requires CNC machining which significantly increases cost and lead time for an iterative research prototype. PLA-Basic has the lowest safety factor (3.02) and highest displacement (0.11 mm) due to the absence of carbon fiber reinforcement. PLA-CF was selected as the optimal material, offering a higher safety factor than PLA-Basic (4.03), lower displacement (0.089 mm), and the same ease of 3D printing — making it the most practical choice for this stage of development.

#### Wellplate Holder Plate — Material Comparison

A second static load analysis (gravity only) was run on the wellplate holder plate — the larger structural plate that carries the entire 96-well plate — using the same three candidate materials.

<table>
  <tr><th align="center">PLA-Basic</th><th align="center">PLA-CF</th><th align="center">Aluminum 6061</th></tr>
  <tr>
    <td align="center"></td>
    <td align="center"></td>
    <td align="center"></td>
  </tr>
  <tr>
    <td align="center"></td>
    <td align="center"></td>
    <td align="center"></td>
  </tr>
</table>

| Metric | PLA-Basic | PLA-CF | Aluminum 6061 |
| :--- | :---: | :---: | :---: |
| Max Von Mises stress | 22.27 MPa | 21.89 MPa | 10.27 MPa |
| Max Displacement | 0.136 mm | 0.131 mm | 0.049 mm |
| Yield Strength (as configured in Inventor) | 34 MPa | 34 MPa | 275 MPa |

#### Insight

Same three-material comparison, different part — the plate that carries the entire wellplate. All three materials keep stress comfortably below their configured yield strength. PLA-CF was again the practical choice here, for the same reason as the stage plate: adequate stiffness at a fraction of the cost and lead time of machining aluminum.

---

### 4. Z-Frame Redesign (Old vs New)

The professor requested a shorter Z-axis assembly. Shortening it meant less material/height in the load path supporting the camera and objective, so the redesign had to be checked against the original for stiffness before committing to it — a shorter frame that flexed more under its own load would defeat the purpose (focus drift during long unattended runs).

<table>
  <tr><th align="center">Old Version</th><th align="center">New Version</th></tr>
  <tr>
    <td align="center"><br/>Von Mises stress</td>
    <td align="center"><br/>Von Mises stress</td>
  </tr>
  <tr>
    <td align="center"><br/>Displacement</td>
    <td align="center"><br/>Displacement</td>
  </tr>
</table>

| Metric | Old Version | New Version |
| :--- | :---: | :---: |
| Von Mises stress (max) | 17.22 MPa | 17.64 MPa |
| Displacement (max) | 2.01 mm | 0.353 mm |

Reference yield strengths: Steel 207 MPa, PLA-Basic 34 MPa — stress stayed far below either material's limit in both versions, so stress was never the concern here.

#### Insight

Stress barely changed (17.22 → 17.64 MPa) but displacement dropped by roughly 82% (2.01 mm → 0.353 mm). The old frame was structurally *safe* but too flexible for a focus-critical application — a shorter Z-axis with the same open frame shape would have flexed even more. The new version adds diagonal cross-bracing at the base, which is what actually fixed the stiffness problem; shortening the frame alone would not have.

---

### 5. Design Iteration

Structural analysis was conducted on motor brackets for all three axes. Each bracket was evaluated across two design iterations.

#### A. X Motor Bracket

<details>
<summary>Previous Version</summary>
<p align="center">
  
  
  
  
</p>
</details>

<details>
<summary>New Version</summary>
<p align="center">
  
  
  
  
</p>
</details>

#### B. Y Motor Bracket

<details>
<summary>Previous Version</summary>
<p align="center">
  
  
  
  
</p>
</details>

<details>
<summary>New Version</summary>
<p align="center">
  
  
  
  
</p>
</details>

#### C. Z Motor Bracket

<details>
<summary>Previous Version</summary>
<p align="center">
  
  
  
  
</p>
</details>

<details>
<summary>New Version</summary>
<p align="center">
  
  
  
  
</p>
</details>

Only displacement was evaluated for these brackets (no stress/safety-factor contour was generated for this analysis, unlike the stage-plate and Z-frame studies above).

| Axis | Previous Version (max, mm) | New Version (max, mm) | Improvement |
| :---: | :---: | :---: | :---: |
| X | 0.04368 | 0.01149 | ~74% reduction |
| Y | 0.4024 | 0.2984 | ~26% reduction |
| Z | 0.003305 | 0.0000134 | ~99.6% reduction |

#### Insight

The Z bracket redesign (adding diagonal cross-bracing, same approach as the [Z-Frame Redesign](#4-z-frame-redesign-old-vs-new) above) essentially solved its flex problem outright. The X bracket saw a solid improvement. The Y bracket is the clear outlier: even after redesign it's still roughly **26× more flexible than X and ~22,000× more flexible than Z** in absolute terms — this is the mechanical root cause behind the [Y-Axis Repeatability](#8-y-axis-repeatability) result being noisier than X and Z, and why the Y-axis assembly remains the top item in [Future Work](#future-work).

---

### 6. Imaging System Design
 
#### Known Variables
 
| Variable | Symbol | Value | Source |
| :--- | :--- | :--- | :--- |
| Nominal tube length | L₀ | 160 mm | Objective spec |
| Nominal magnification | M₀ | 10x | Objective spec |
| Sensor width | Sw | 6.287 mm | IMX477 datasheet |
| Sensor height | Sh | 4.712 mm | IMX477 datasheet |
| Sensor resolution (H × V) | Rw × Rh | 4056 × 3040 px | IMX477 datasheet |
| Pixel size | p | 1.55 × 1.55 µm | IMX477 datasheet |
 
> **Verification:** `Sw = p × Rw = 1.55µm × 4056 = 6.287mm` ✅
 
#### Formulas & Derivations
 
**1. Actual Magnification at a Given Tube Length**
 
Magnification in a lens system is defined as the ratio of image distance to object distance. Since the sample is always fixed at the objective's focal plane, only the image distance (tube length) changes. Therefore magnification scales linearly with tube length:
 
$$M_{actual} = M_0 \times \frac{L_{actual}}{L_0}$$
 
> ⚠️ Valid as an approximation near the nominal tube length (160mm). Larger deviations introduce spherical aberrations — empirical validation is required.
 
**2. Field of View**
 
Rearranging the definition of magnification (`M = image size / object size`), the real-world size captured by the sensor is:
 
$$FOV_{horizontal} = \frac{S_w}{M_{actual}} \qquad FOV_{vertical} = \frac{S_h}{M_{actual}}$$
 
**3. Limiting FOV (circular samples)**
 
The sensor is rectangular but wellplates are circular. The vertical axis (shorter side) is the limiting dimension:
 
$$FOV_{limiting} = FOV_{vertical} = \frac{S_h}{M_{actual}}$$
 
**4. Required Tube Length for a Target FOV**
 
Combining formulas 1 and 2 and solving for tube length:
 
$$L_{target} = \frac{S_h \times L_0}{M_0 \times FOV_{target}}$$
 
**5. Empirical Scale (known bead size)**
 
If the real diameter of a reference bead is known, pixel scale and FOV can be derived directly from image measurements:
 
$$\mu m/pixel = \frac{d_{bead,real}}{d_{bead,pixel}} \qquad M_{actual} = \frac{S_w}{FOV_{horizontal}} \times 1000$$
 
**6. Empirical FOV Ratio (unknown bead size)**
 
If bead size is unknown but the same beads are imaged at two different tube lengths, the FOV ratio can be derived purely from pixel measurements — no real size needed:
 
$$\frac{FOV_1}{FOV_2} = \frac{L_2}{L_1} = \frac{d_{bead,px,2}}{d_{bead,px,1}}$$
 
#### Tube Length Selection — 96-well Plate (well diameter = 9 mm)
 
Five tube lengths were selected for empirical testing, each with a distinct optical rationale:
 
| # | Tube Length | Magnification | FOV Horizontal | FOV Vertical | Rationale |
| :---: | :--- | :--- | :--- | :--- | :--- |
| 1 | 160 mm | 10x | 628.7 µm | 471.2 µm | Nominal objective spec — baseline reference |
| 2 | 8.4 mm | 0.525x | 11.97 mm | 9.00 mm | FOV vertical = 9mm — fits entire well height |
| 3 | 11.2 mm | 0.70x | 8.98 mm | 6.73 mm | FOV horizontal = 9mm — fits entire well width |
| 4 | **84.2 mm ✅** | 5.26x | 1.20 mm | 0.90 mm | Midpoint between nominal and shortest — gradual aberration check. **Selected as the final tube length** — its magnification most closely matched the professional lab microscope reference. |
| 5 | 64 mm | 4x | 1.57 mm | 1.18 mm | 4x magnification — evaluate mid-range image quality |
 
**Derivations:**
 
$$L_2 = \frac{S_h \times L_0}{M_0 \times FOV_{target}} = \frac{4.712 \times 160}{10 \times 9} \approx 8.4\ \text{mm}$$
 
$$L_3 = \frac{S_w \times L_0}{M_0 \times FOV_{target}} = \frac{6.287 \times 160}{10 \times 9} \approx 11.2\ \text{mm}$$
 
$$L_4 = \frac{8.4 + 160}{2} = 84.2\ \text{mm}$$
 
$$L_5 = \frac{4}{10} \times 160 = 64\ \text{mm}$$
 
#### Imaging Validation

Imaging validation was conducted in two stages: first using microbeads as a controlled reference target to evaluate optical performance across tube lengths, then using spheroids as the actual biological sample to confirm suitability for long-term live-cell imaging.

---

##### Stage 1 — Microbead Imaging

Microbeads were used as a controlled reference target to characterize optical performance across tube lengths. Each tube length was tested at two objective configurations (10x and 4x) to evaluate sharpness, chromatic aberration, and overall image quality before proceeding to biological samples.

**Reference — Professional Lab Microscope**

Images captured using a professional laboratory microscope as ground truth reference for image quality comparison.

<table>
  <tr>
    <th align="center">Magnification</th>
    <th align="center">Image</th>
  </tr>
  <tr>
    <td align="center">4x</td>
    <td align="center"></td>
  </tr>
  <tr>
    <td align="center">10x</td>
    <td align="center"></td>
  </tr>
</table>

###### 🔬 Objective Lens 10x

<table>
  <tr>
    <th align="center">#</th>
    <th>Tube Length</th>
    <th align="center">Microbeads</th>
    <th align="center">Microbeads + Light</th>
    <th>Notes</th>
  </tr>
  <tr>
    <td align="center">1</td>
    <td>160 mm</td>
    <td align="center"></td>
    <td align="center"></td>
    <td>Severely out of focus — despite being the objective's nominal spec, beads appear as one large unresolvable blur with no visible edges. The nominal tube length did not translate directly to good focus at this working distance.</td>
  </tr>
  <tr>
    <td align="center">2</td>
    <td>8.4 mm</td>
    <td align="center"></td>
    <td align="center"></td>
    <td>Sharp — bead edges and fine surface debris are clearly resolved.</td>
  </tr>
  <tr>
    <td align="center">3</td>
    <td>11.2 mm</td>
    <td align="center"></td>
    <td align="center"></td>
    <td>Sharp — comparable resolution to 8.4 mm, clean bead edge definition.</td>
  </tr>
  <tr>
    <td align="center">4</td>
    <td>84.2 mm</td>
    <td align="center"></td>
    <td align="center"></td>
    <td>Bead edges are defined but internal detail is soft — noticeably less sharp than the shorter tube lengths.</td>
  </tr>
  <tr>
    <td align="center">5</td>
    <td>64 mm</td>
    <td align="center"></td>
    <td align="center"></td>
    <td>Sharp — bead edges and internal ring texture are clearly resolved.</td>
  </tr>
  <tr>
    <td align="center">6</td>
    <td>72 mm (4.5x Magnification)</td>
    <td align="center"></td>
    <td align="center"></td>
    <td>Edges are reasonably defined but softer overall than 64 mm or 80 mm — intermediate sharpness.</td>
  </tr>
  <tr>
    <td align="center">7</td>
    <td>80 mm (5x Magnification)</td>
    <td align="center"></td>
    <td align="center"></td>
    <td>Sharp — fine features (a stray fiber in frame) are crisply resolved.</td>
  </tr>
</table>

---

###### 🔬 Objective Lens 4x

<table>
  <tr>
    <th align="center">#</th>
    <th>Tube Length</th>
    <th align="center">Microbeads</th>
    <th align="center">Microbeads + Light</th>
    <th>Notes</th>
  </tr>
  <tr>
    <td align="center">1</td>
    <td>160 mm</td>
    <td align="center"></td>
    <td align="center"></td>
    <td>Mixed — beads toward the frame edges show reasonably defined edges, but a large soft, hazy artifact (likely an air bubble out of the focal plane) dominates the center of the frame.</td>
  </tr>
  <tr>
    <td align="center">2</td>
    <td>8.4 mm</td>
    <td align="center"></td>
    <td align="center"></td>
    <td>Out of focus at this tube length with 4x objective — the combination of short tube length and lower base magnification places the image plane outside the usable focus range.</td>
  </tr>
  <tr>
    <td align="center">3</td>
    <td>11.2 mm</td>
    <td align="center"></td>
    <td align="center"></td>
    <td>Out of focus at this tube length with 4x objective — same constraint as 8.4 mm. These two tube lengths are outside the practical operating range for the 4x objective.</td>
  </tr>
  <tr>
    <td align="center">4</td>
    <td>84.2 mm</td>
    <td align="center"></td>
    <td align="center"></td>
    <td>Sharp — bead edges and fine background debris/bubbles are clearly resolved.</td>
  </tr>
  <tr>
    <td align="center">5</td>
    <td>64 mm</td>
    <td align="center"></td>
    <td align="center"></td>
    <td>Sharp — wide field with many beads in crisp focus; fine hair fibers in the frame are clearly resolved.</td>
  </tr>
  <tr>
    <td align="center">6</td>
    <td>72 mm</td>
    <td align="center"></td>
    <td align="center"></td>
    <td>Sharp — bead edges clearly defined, consistent with the other 4x results.</td>
  </tr>
  <tr>
    <td align="center">7</td>
    <td>80 mm</td>
    <td align="center"></td>
    <td align="center"></td>
    <td>Sharp — bead edges and fine bubbles/debris in the background are clearly resolved.</td>
  </tr>
</table>

---

##### Stage 2 — Spheroid Imaging

With the microbead calibration narrowing down usable tube lengths, the same three candidates (160 mm, 84.2 mm, 80 mm) were imaged against the actual biological sample — spheroids in a wellplate — at both objectives, to confirm the calibration holds up on a real, non-flat, 3D target.

**Reference — Professional Lab Microscope**

Images captured using a professional laboratory microscope as ground truth reference for image quality comparison.

<table>
  <tr>
    <th align="center">Magnification</th>
    <th align="center">Image</th>
  </tr>
  <tr>
    <td align="center">4x</td>
    <td align="center"></td>
  </tr>
  <tr>
    <td align="center">10x</td>
    <td align="center"></td>
  </tr>
</table>

###### 🔬 Objective Lens 10x

<table>
  <tr>
    <th align="center">#</th>
    <th>Tube Length</th>
    <th align="center">Spheroids</th>
    <th align="center">Spheroids + Light</th>
    <th>Notes</th>
  </tr>
  <tr>
    <td align="center">1</td>
    <td>160 mm</td>
    <td align="center"></td>
    <td align="center"></td>
    <td>Good — individual cell boundaries on the spheroid surface are resolved, comparable in sharpness to the professional microscope reference. Unlike the microbead test, 160 mm is not a poor result for spheroids.</td>
  </tr>
  <tr>
    <td align="center">4</td>
    <td>84.2 mm</td>
    <td align="center"></td>
    <td align="center"></td>
    <td>Good — spheroid surface texture and a nearby smaller cell cluster are both clearly resolved.</td>
  </tr>
  <tr>
    <td align="center">7</td>
    <td>80 mm</td>
    <td align="center"></td>
    <td align="center"></td>
    <td>Good — spheroid surface texture is clearly resolved, including a fine fiber crossing the frame.</td>
  </tr>
</table>

---

###### 🔬 Objective Lens 4x

<table>
  <tr>
    <th align="center">#</th>
    <th>Tube Length</th>
    <th align="center">Spheroids</th>
    <th align="center">Spheroids + Light</th>
    <th>Notes</th>
  </tr>
  <tr>
    <td align="center">1</td>
    <td>160 mm</td>
    <td align="center"></td>
    <td align="center"></td>
    <td>Good — the spheroid itself is in sharp focus with visible surface texture; an unrelated dark object elsewhere in frame is out of the focal plane, but doesn't reflect on the spheroid's own sharpness.</td>
  </tr>
  <tr>
    <td align="center">4</td>
    <td>84.2 mm</td>
    <td align="center"></td>
    <td align="center"></td>
    <td>Soft — the spheroid is visible but lower-contrast than the 160 mm and 80 mm results, with more out-of-focus debris in the background.</td>
  </tr>
  <tr>
    <td align="center">7</td>
    <td>80 mm</td>
    <td align="center"></td>
    <td align="center"></td>
    <td>Out of focus — most of the frame is blurred; only a small spheroid at the frame edge is marginally resolved. The weakest result in the spheroid set.</td>
  </tr>
</table>

---

#### Insight

Empirical testing overturned the naive assumption that the nominal 160 mm tube length (the objective's own spec) would give the best focus. For microbeads at 10x, 160 mm was actually the *worst* result in the set — a single unresolvable blur — while several shorter/longer candidates (8.4 mm, 11.2 mm, 64 mm, 80 mm) were sharp. At 4x, all four tested lengths held up consistently well for microbeads.

For the actual spheroid samples, 10x was reliably good across every tube length tested (160 mm, 84.2 mm, 80 mm), landing close to the professional reference microscope. 4x was more inconsistent (160 mm good, 84.2 mm soft, 80 mm largely out of focus) — likely reflecting where that particular spheroid happened to sit along Z that day rather than a property of the tube length itself, since a real spheroid is a 3D object and not a flat calibration target like the microbeads.

**Final choice: 84.2 mm at 10x**, confirmed with the supervisor and professor — its magnification most closely matched the professional lab microscope reference, out of all the candidates tested against both microbeads and real spheroid samples.

**Takeaway:** 10x is the more dependable objective for this system, and tube length can't be trusted from the nominal spec alone — it has to be empirically confirmed per setup, exactly as done here.

###

---

### 7. X-Axis Repeatability

Positioning repeatability was measured using phase correlation on paired images: the stage moves from well A1 to well A12 and back, 50 times, and each returning image is compared against the A1 baseline image to measure sub-pixel drift.

<p align="center">
  
</p>

| Metric | Value (px) | Value (µm, @ 1.55 µm/px) |
| :--- | :---: | :---: |
| Mean distance | 0.082 | 0.13 |
| Std dev | 0.043 | 0.07 |
| Max distance | 0.170 | 0.26 |
| Mean dx | +0.055 | — |
| Mean dy | +0.014 | — |

#### Insight

Sub-micron repeatability (mean 0.13 µm, max 0.26 µm) — the X-axis consistently returns to the same position across all 50 cycles, with no visible trend or drift in the displacement plot.

---

### 8. Y-Axis Repeatability

Same phase-correlation method as the X-axis test, moving between well A1 and well E1, 50 cycles.

<p align="center">
  
</p>

| Metric | Value (px) | Value (µm, @ 1.55 µm/px) |
| :--- | :---: | :---: |
| Mean distance | 0.241 | 0.37 |
| Std dev | 0.242 | 0.38 |
| Max distance | 1.102 | 1.71 |
| Mean dx | +0.051 | — |
| Mean dy | −0.013 | — |

#### Insight

The Y-axis is measurably less consistent than X and Z: mean error (0.37 µm) is about 3× the X-axis's, and the standard deviation (0.38 µm) is almost as large as the mean itself — several cycles show a sharp displacement spike (up to 1.71 µm) rather than a tight, flat band like the X-axis result. This matches physical observation of vibration during Y-axis movement. The numbers aren't catastrophic in absolute terms (sub-2-micron), but the inconsistency is the reason the Y-axis mechanical assembly is flagged for revision — see [Future Work](#future-work).

<p align="center">
  
  <br/><sub>The stage in motion during an automated scan — illustrative of the general motion behavior, not an isolated measurement of the Y-axis defect above.</sub>
</p>

---

### 9. Z-Axis Focus Repeatability

To verify that the anti-backlash nut effectively eliminates positional error on the Z-axis, a repeatability test was conducted after assembly.
[📄 View Full Analysis Result (PDF)](./mechanical/focus_report.html)

#### Method

The Z-axis was positioned to a reference focal plane and set as baseline. For each cycle, the stage moves down a fixed number of steps then returns to baseline. A sharpness score is computed from each captured image using **Laplacian Variance** — a focus metric that measures high-frequency edge content in the image. Higher variance = sharper image = better focus.

$$\text{Sharpness} = \text{Var}\left(\nabla^2 I\right)$$

**Coefficient of Variation (CV%)** is used as the repeatability indicator — lower CV means the Z-axis consistently returns to the same focal plane.

#### Test Parameters

| Parameter | Value |
| :--- | :--- |
| Cycles | 50 |
| Z displacement per cycle | 500 steps (2.5 mm) |
| Focus metric | Laplacian Variance |

#### Results

| Metric | Value |
| :--- | :--- |
| Mean sharpness | 3.3123 |
| Std Dev | 0.0467 |
| Min / Max | 3.1869 / 3.3926 |
| **CV (%)** | **1.41%** |

CV of **1.41%** — well below the 2% threshold for excellent repeatability. Visual inspection of all 50 images confirmed consistent focus with no visible defocus across any cycle.

#### Insight

The anti-backlash nut successfully eliminates Z-axis positional error. The lead screw + anti-backlash nut + NEMA17 combination delivers consistent focal plane return across repeated cycles, confirming suitability for long-term automated imaging.

---

### 10. Thermal Consideration

Thermal images of each stepper motor and the well plate under 24/7 operating conditions:

<p align="center">
  
  
  
  
</p>

Readings taken directly off the thermal camera's on-screen measurement points:

| Target | Measured point temperature | Frame center |
| :--- | :--- | :--- |
| X motor | up to 44.2°C | 30.0°C |
| Y motor | up to 45.8°C | 25.6°C |
| Z motor | up to 41.3°C | 41.3°C |
| Wellplate | 24.6–25.0°C across all points | 24.6°C |

Each frame also reports a "Max" of ~55°C, consistent across all four shots regardless of target — likely an unrelated hot spot elsewhere in the camera's field of view rather than the motor or wellplate itself, so it isn't included as a per-component reading above.

The motors run warm (low-to-mid 40s °C) under test, but the wellplate itself stays essentially at room temperature (~24–25°C) — which is the reading that actually matters for keeping live cell samples viable during a 24/7 run inside an incubator.

---

### 11. Engineering Drawing

> 🚧 **In progress** — engineering drawings and GD&T specifications to be added.

---

### 12. Mechanical Insight

Across every structural analysis in this section, the same pattern holds: **stress was never the limiting factor — stiffness (displacement) was.** The stage plate, the wellplate holder plate, the Z-frame, and the motor brackets all showed comfortable margin on stress even in their original designs; what actually needed fixing was how much they physically flexed under load, since flex translates directly into focus drift and positioning error in a system built around micron-scale repeatability.

PLA-CF was chosen as the standard material for exactly this reason — it isn't the stiffest option available (aluminum is, in both material comparisons above), but it's stiff enough for every part tested, and dramatically easier and cheaper to iterate on via 3D printing. That iteration speed mattered more for a prototype still being revised part by part than aluminum's extra stiffness would have. Where a design genuinely needed more stiffness (the Z bracket, the Z-frame), the fix was structural — adding cross-bracing — rather than a material swap.

The X and Z axes responded well to this approach: the Z bracket redesign essentially solved its flex problem outright, and the Z-frame shortened as requested without giving up stiffness. The Y-axis is the outlier — even after the same kind of redesign, it remains the least stiff and least repeatable axis by a wide margin (see [Design Iteration](#5-design-iteration) and [Y-Axis Repeatability](#8-y-axis-repeatability)), which is why it's the top item in [Future Work](#future-work) rather than considered solved.

---

## ⚡ Electrical

### 1. Components & Specs

| Component | Part Number | Specification | Quantity |
| :--- | :--- | :--- | :---: |
| PSU (Logic) | Meanwell LRS-35-5 | 5V, 7A | 1 |
| PSU (Motor) | Meanwell LRS-100-12 | 12V, 8.3A | 1 |
| Stepper Motor | NEMA17 42-40 | 1.8°/step, 200 steps/rev | 3 |
| Motor Driver | DRV8825 (Pololu Breakout) | Up to 1/32 microstepping | 3 |
| TVS Diode | D_TVS 18V | Motor back-EMF protection | 3 |
| MCU | Arduino Nano V3 | ATmega328P, 5V logic | 1 |
| SBC | Raspberry Pi 4 | 3.3V logic | 1 |
| Level Shifter | Bidirectional LLC | 5V ↔ 3.3V | 1 |
| AC Input | IEC C14 Receptacle | — | 1 |
| Fuse (AC) | — | 3A Slow Blow | 1 |
| Fuse (Motor) | — | 5A | 1 |
| Polyfuse (Logic) | — | 3A Resettable | 1 |
| Capacitor | C_Polarized | 100µF, decoupling per motor driver | 3 |
| Capacitor | C_Polarized | 470µF, logic rail bulk | 1 |
| Capacitor | C | 0.1µF, decoupling | 7 |

---

### 2. Schematic

[📄 View Full Schematic (PDF)](./electrical/elec_sch.pdf)

The schematic is organized into 4 sheets:

| Sheet | Title | Description |
| :--- | :--- | :--- |
| 1 | System Overview | Top-level hierarchy showing how all sheets interconnect |
| 2 | AC Input & Primary Power | Converts 220V AC mains to regulated 5V and 12V DC rails, with slow-blow fusing and earth protective ground |
| 3 | 12V Motor Power Domain | Three independent DRV8825 motor driver circuits with TVS back-EMF protection and bulk capacitors, driving NEMA17 stepper motors for X, Y, and Z axes |
| 4 | 5V Logic Domain | Raspberry Pi 4 and Arduino Nano V3 connected via bidirectional level shifter, with limit switches and polyfuse protection on the logic rail |

### 3. Calculations

**Power budget (approximate, based on component ratings — not bench-measured):**

- **12V motor rail** (Meanwell LRS-100-12, 100W / 8.3A): three NEMA17 42-40 steppers via DRV8825 drivers, typically drawing roughly 1–1.5A per phase for this motor class. Worst case — all three axes driven at once — is around 3–4.5A, comfortably under the 8.3A rating. In practice this stage rarely drives more than one or two axes simultaneously.
- **5V logic rail** (Meanwell LRS-35-5, 35W / 7A): Raspberry Pi 4 (up to ~3A under load) plus the level shifter, limit switches, and the Arduino's logic-side draw — well within the 7A rating, with the 470µF bulk capacitor there specifically to absorb the Pi's inrush current rather than let it sag the rail.

**Signal flow:** AC mains → IEC inlet → fused split into the two DC rails → 12V rail fans out through three TVS-protected DRV8825 drivers to the steppers; 5V rail powers the Pi and Arduino directly, with the level shifter sitting between their GPIO/UART lines.

### 4. Electrical Insight

- **Dual PSU instead of one:** splitting logic (5V) and motors (12V) onto separate supplies keeps the noisy, current-hungry stepper drivers from sagging or injecting noise into the sensitive Pi/Arduino logic rail every time a motor starts or stops.
- **Fused per rail, not just at the mains inlet:** the slow-blow fuse at the IEC inlet protects the AC side, but independent fuses on each DC rail (3A logic, 5A motor) mean a fault on one rail doesn't necessarily take the other down with it.
- **TVS diodes on every motor driver:** steppers generate back-EMF when they decelerate or stop abruptly — the TVS diodes clamp that voltage spike before it reaches (and potentially damages) the DRV8825 driver ICs.
- **Level shifter between Pi and Arduino:** the Pi's GPIO runs at 3.3V and the Arduino Nano at 5V — the bidirectional shifter is required here, not optional, to avoid over-volting the Pi's inputs or under-driving the Arduino's.

---

## 💻 Software

### 1. Architecture
 
#### 1.1 System Overview
 
The system is split across two processors with clearly separated responsibilities. The Raspberry Pi 4 handles all high-level tasks — running the Flask web server, managing the experiment loop, controlling the camera, and serving the browser-based GUI. The Arduino Nano V3 handles all real-time low-level tasks — generating STEP/DIR pulses for the three stepper motors, polling limit switches, and controlling the shared SLP pin for driver sleep/wake. Communication between the two is via UART serial (currently USB cable, migrating to TX/RX via bidirectional level shifter).
 
System Overview
 
#### 1.2 Software Flow
 
The web GUI runs in any browser on the same network. User actions hit Flask REST endpoints, which dispatch commands to the SerialManager (for motor moves) or CameraManager (for captures). The ExperimentRunner runs as a background thread, orchestrating the full 24/7 scan cycle independently of the GUI.
 
Software Flow
 
#### 1.3 Experiment Loop
 
Each round begins with an autofocus sweep at the reference well (A1) using the Tenengrad focus metric. The stage then visits every well in serpentine order — move, settle, capture, repeat. After all 96 wells are done, the system waits for the configured interval, then checks whether the experiment end time has been reached. If not, it starts the next round. If yes, the experiment ends automatically.
 
Experiment Loop
 
#### 1.4 Repository Structure
 
```
Automation-Incubator-Microscope/
├── backend/
│   └── app.py              # Flask server — routes, ExperimentRunner, CameraManager, SerialManager
├── frontend/
│   ├── index.html          # Web GUI — stage controls, experiment panel, live status
│   └── assets/
│       └── imbsllogo.png
├── firmware/
│   └── sketch_oct03a.ino   # Arduino Nano V3 — STEP/DIR, SLP, limit switches, stop
├── config.json             # Runtime config — interval, settle delay, storage path, Z range
└── README.md
```
 
---
 
### 2. Firmware
 
The Arduino firmware (`sketch_oct03a.ino`) handles all real-time hardware tasks. It listens for serial commands from the Raspberry Pi and executes them deterministically without OS interference.
 
#### Serial Command Reference
 
| Command | Action |
| :--- | :--- |
| `A1` … `H12` | Move to specified well |
| `home` | Home X and Y axes to limit switches |
| `scan` | Home then serpentine scan all 96 wells |
| `U` | Z axis up one increment |
| `D` | Z axis down one increment |
| `sleep` | Set SLP HIGH — all drivers enter low-power sleep |
| `wake` | Set SLP LOW — all drivers become active |
| `stop` | Abort current movement or scan mid-operation |
 
---
 
### 3. GUI
 
The GUI is a single-page web app served by Flask, accessible from any browser on the same network as the Raspberry Pi. It is built with plain HTML, Tailwind CSS, and vanilla JavaScript — no build step required.
 
**Stage controls** — Home, Z Up, Z Down, Autofocus, Scan All, Stop, Reset Busy are always visible at the top. The 96-well grid below highlights the current well position in real time (polled every 1 second).
 
**Experiment panel** — sits below the grid. User fills in Experiment ID (optional), capture interval, settle delay, storage path, autofocus Z range, and end date/time. Pressing Start saves the settings to `config.json` and launches the experiment loop. A live status box shows round number, total images captured, countdown to next scan, and experiment end time.
 
---
 
### 4. Data Management
 
#### 4.1 Pipeline
 
Every captured image goes through a three-step pipeline immediately after capture: raw array from Picamera2 → BGR conversion → grayscale conversion via OpenCV. Both the raw PNG and grayscale PNG are saved side by side. The original is retained for potential reprocessing.
 
Data Pipeline
 
#### 4.2 Folder Structure
 
```
/data/
└── EXP_001_20260401/
    ├── metadata.json           ← experiment parameters
    ├── A1/
    │   ├── 20260401_080000_A1_r001_raw.png
    │   ├── 20260401_080000_A1_r001_gray.png
    │   └── ...
    ├── A2/
    └── ...
```
 
#### 4.3 File Naming Convention
 
```
YYYYMMDD_HHMMSS_[WellID]_r[Round]_[type].png
```
 
| Field | Example | Description |
| :--- | :--- | :--- |
| YYYYMMDD | 20260401 | Date of capture |
| HHMMSS | 080000 | Time of capture (24h) |
| WellID | A1, B3, H12 | Well position |
| Round | r001, r012 | Scan round index |
| type | raw / gray | Original or grayscale |
 
#### 4.4 Metadata
 
Each experiment generates a `metadata.json` at the experiment root:
 
```json
{
  "experiment_id": "EXP_001_20260401",
  "start_time": "2026-04-01T08:00:00",
  "end_time": "2026-04-08T08:00:00",
  "capture_interval_hours": 2,
  "settle_delay_ms": 500,
  "autofocus_z_range": 20,
  "autofocus_step_size": 1
}
```
 
#### 4.5 Storage Estimate
 
For a 96-well plate, captured every 2 hours over 7 days, saving grayscale PNG (~2 MB each):
 
```
96 wells × 12 captures/day × 7 days = 8,064 images ≈ 16 GB/week
```
 
Recommended storage: USB SSD 256 GB connected to Raspberry Pi.
 
---

### 5. Software Insight

Splitting responsibilities between the Raspberry Pi and Arduino wasn't arbitrary — it maps each task to the processor actually suited for it. Motor step/direction pulses need precise timing and can't tolerate an OS scheduler getting in the way, so that stays on the Arduino's bare-metal loop. Everything else — the web server, experiment scheduling, image capture and processing — benefits from a full OS, filesystem, and Python ecosystem, so that lives on the Pi. UART between them is a deliberately simple choice: a small, well-understood command set (`A1`, `home`, `scan`, `stop`, …) that's easy to debug over a serial monitor, instead of a heavier protocol that would add complexity without adding capability at this scale.

The data pipeline (raw + grayscale PNG side by side, per-well folders, one `metadata.json` per experiment) is deliberately redundant: keeping the raw capture alongside the processed grayscale version means a bug in the grayscale conversion — or a future need for a different processing pipeline entirely — doesn't require re-running the physical experiment to recover the original data.

---

## Future Work

This is an active lab tool, not a finished product — the following is what's known to still need work, in the order it needs to happen:

1. **Revise the Y-axis mechanical assembly** to eliminate the vibration observed during motor movement (see [Y-Axis Repeatability](#8-y-axis-repeatability)).
2. **Add a voltage divider resistor** between the Raspberry Pi and Arduino Nano for stable UART communication — communication currently works with an example/test program, but hasn't been finished for the actual control pipeline.
3. **Extend the stepper motor cables** to improve routing and reduce mechanical strain.
4. **Decide the autofocus strategy** (once at the start of a scan vs. per-well) — deferred until Y-axis repeatability is confirmed, since autofocus quality depends on the stage actually landing in the same place each time.

---

## 📁 Repository Structure

```
Automation-Incubator-Microscope/
├── src/                    # Images and media assets
├── mechanical/             # CAD files and FEA results
│   ├── stage-plate/
│   ├── motor-brackets/
│   └── drawings/
├── electrical/             # Schematics and BOM
├── software/               # Firmware and control scripts
├── docs/                   # Additional documentation
└── README.md
```

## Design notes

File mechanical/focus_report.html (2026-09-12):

# Z-Axis Focus Repeatability Report

Source: focus_results_20260410_092916.csv | Generated: 2026-04-10 11:02:13

Mean sharpness

2.1344

Standard deviation

0.0251

Coefficient of variation

1.18%

EXCELLENT

Minimum sharpness

2.0928

Maximum sharpness

2.2038

Cycles tested

50

## Sharpness per cycle

## Raw sharpness data

Cycle | Sharpness
1 | 2.2038
2 | 2.1452
3 | 2.1455
4 | 2.1627
5 | 2.1262
6 | 2.1625
7 | 2.1146
8 | 2.1510
9 | 2.1452
10 | 2.1308
11 | 2.1520
12 | 2.1435
13 | 2.1265
14 | 2.1499
15 | 2.1316
16 | 2.1292
17 | 2.1192
18 | 2.0938
19 | 2.1363
20 | 2.0928
21 | 2.1165
22 | 2.0942
23 | 2.1224
24 | 2.0973
25 | 2.1040
26 | 2.1271
27 | 2.1321
28 | 2.1494
29 | 2.1136
30 | 2.1189
31 | 2.0989
32 | 2.1205
33 | 2.1838
34 | 2.1322
35 | 2.1622
36 | 2.1049
37 | 2.1204
38 | 2.1367
39 | 2.1538
40 | 2.1127
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

## Image gallery

Cycle 1

Sharpness: 2.2038

Cycle 2

Sharpness: 2.1452

Cycle 3

Sharpness: 2.1455

Cycle 4

Sharpness: 2.1627

Cycle 5

Sharpness: 2.1262

Cycle 6

Sharpness: 2.1625

Cycle 7

Sharpness: 2.1146

Cycle 8

Sharpness: 2.1510

Cycle 9

Sharpness: 2.1452

Cycle 10

Sharpness: 2.1308

Cycle 11

Sharpness: 2.1520

Cycle 12

Sharpness: 2.1435

Cycle 13

Sharpness: 2.1265

Cycle 14

Sharpness: 2.1499

Cycle 15

Sharpness: 2.1316

Cycle 16

Sharpness: 2.1292

Cycle 17

Sharpness: 2.1192

Cycle 18

Sharpness: 2.0938

Cycle 19

Sharpness: 2.1363

Cycle 20

Sharpness: 2.0928

Cycle 21

Sharpness: 2.1165

Cycle 22

Sharpness: 2.0942

Cycle 23

Sharpness: 2.1224

Cycle 24

Sharpness: 2.0973

Cycle 25

Sharpness: 2.1040

Cycle 26

Sharpness: 2.1271

Cycle 27

Sharpness: 2.1321

Cycle 28

Sharpness: 2.1494

Cycle 29

Sharpness: 2.1136

Cycle 30

Sharpness: 2.1189

Cycle 31

Sharpness: 2.0989

Cycle 32

Sharpness: 2.1205

Cycle 33

Sharpness: 2.1838

Cycle 34

Sharpness: 2.1322

Cycle 35

Sharpness: 2.1622

Cycle 36

Sharpness: 2.1049

Cycle 37

Sharpness: 2.1204

Cycle 38

Sharpness: 2.1367

Cycle 39

Sharpness: 2.1538

Cycle 40

Sharpness: 2.1127

Cycle 41

Sharpness: 2.1342

Cycle 42

Sharpness: 2.1442

Cycle 43

Sharpness: 2.1300

Cycle 44

Sharpness: 2.1367

Cycle 45

Sharpness: 2.1864

Cycle 46

Sharpness: 2.1135

Cycle 47

Sharpness: 2.1787

Cycle 48

Sharpness: 2.1156

Cycle 49

Sharpness: 2.1368

Cycle 50

Sharpness: 2.1817

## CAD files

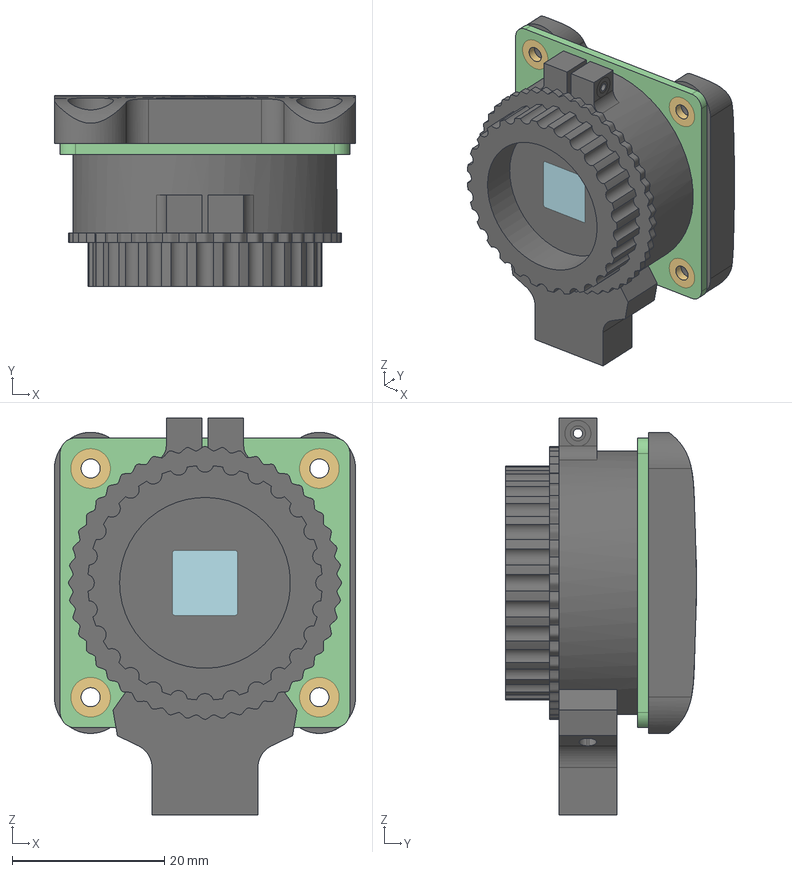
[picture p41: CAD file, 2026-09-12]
mechanical/3d_design/microscope/raspberry-pi-global-shutter-camera-1.snapshot.4/Raspberry Pi Global Shutter Camera.step
39.5 x 25.1 x 52.1 mm

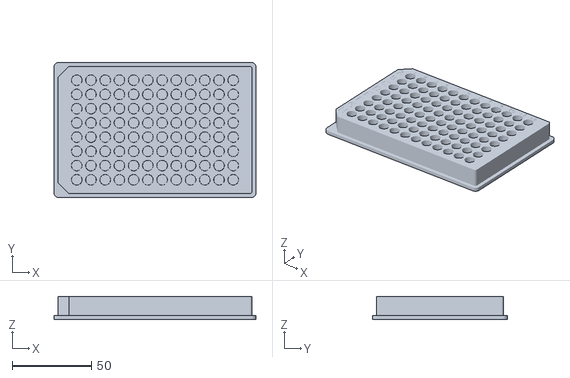
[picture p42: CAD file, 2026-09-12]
mechanical/3d_design/wellplate/96 Well Plate, F-bottom, Standard - 96 Well Plate, F-bottom, Standard.stl
127.8 x 85.5 x 14.6

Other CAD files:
mechanical/3d_design/wellplate/96 Well Plate, F-bottom, Standard.step
mechanical/3d_design/microscope/10x_objective_lens_finite_160mm.ipt
mechanical/3d_design/microscope/KFL08-KFL08-Part/DIN_916-M3x3.ipt
mechanical/3d_design/microscope/KFL08-KFL08-Part/KFL08-KFL08-Part.iam
mechanical/3d_design/microscope/KFL08-KFL08-Part/KFL08Bearing.ipt
mechanical/3d_design/microscope/KFL08-KFL08-Part/KFL08Housing.ipt
mechanical/3d_design/microscope/KFL08-KFL08-Part/OldVersions/DIN_916-M3x3.0001.ipt
mechanical/3d_design/microscope/KFL08-KFL08-Part/OldVersions/KFL08-KFL08-Part.0002.iam
mechanical/3d_design/microscope/KFL08-KFL08-Part/OldVersions/KFL08Bearing.0001.ipt
mechanical/3d_design/microscope/KFL08-KFL08-Part/OldVersions/KFL08Housing.0001.ipt
mechanical/3d_design/microscope/MGN12H_With_Rail x axis/MGN12H.iam
mechanical/3d_design/microscope/MGN12H_With_Rail x axis/MGN12H_Ball.ipt
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

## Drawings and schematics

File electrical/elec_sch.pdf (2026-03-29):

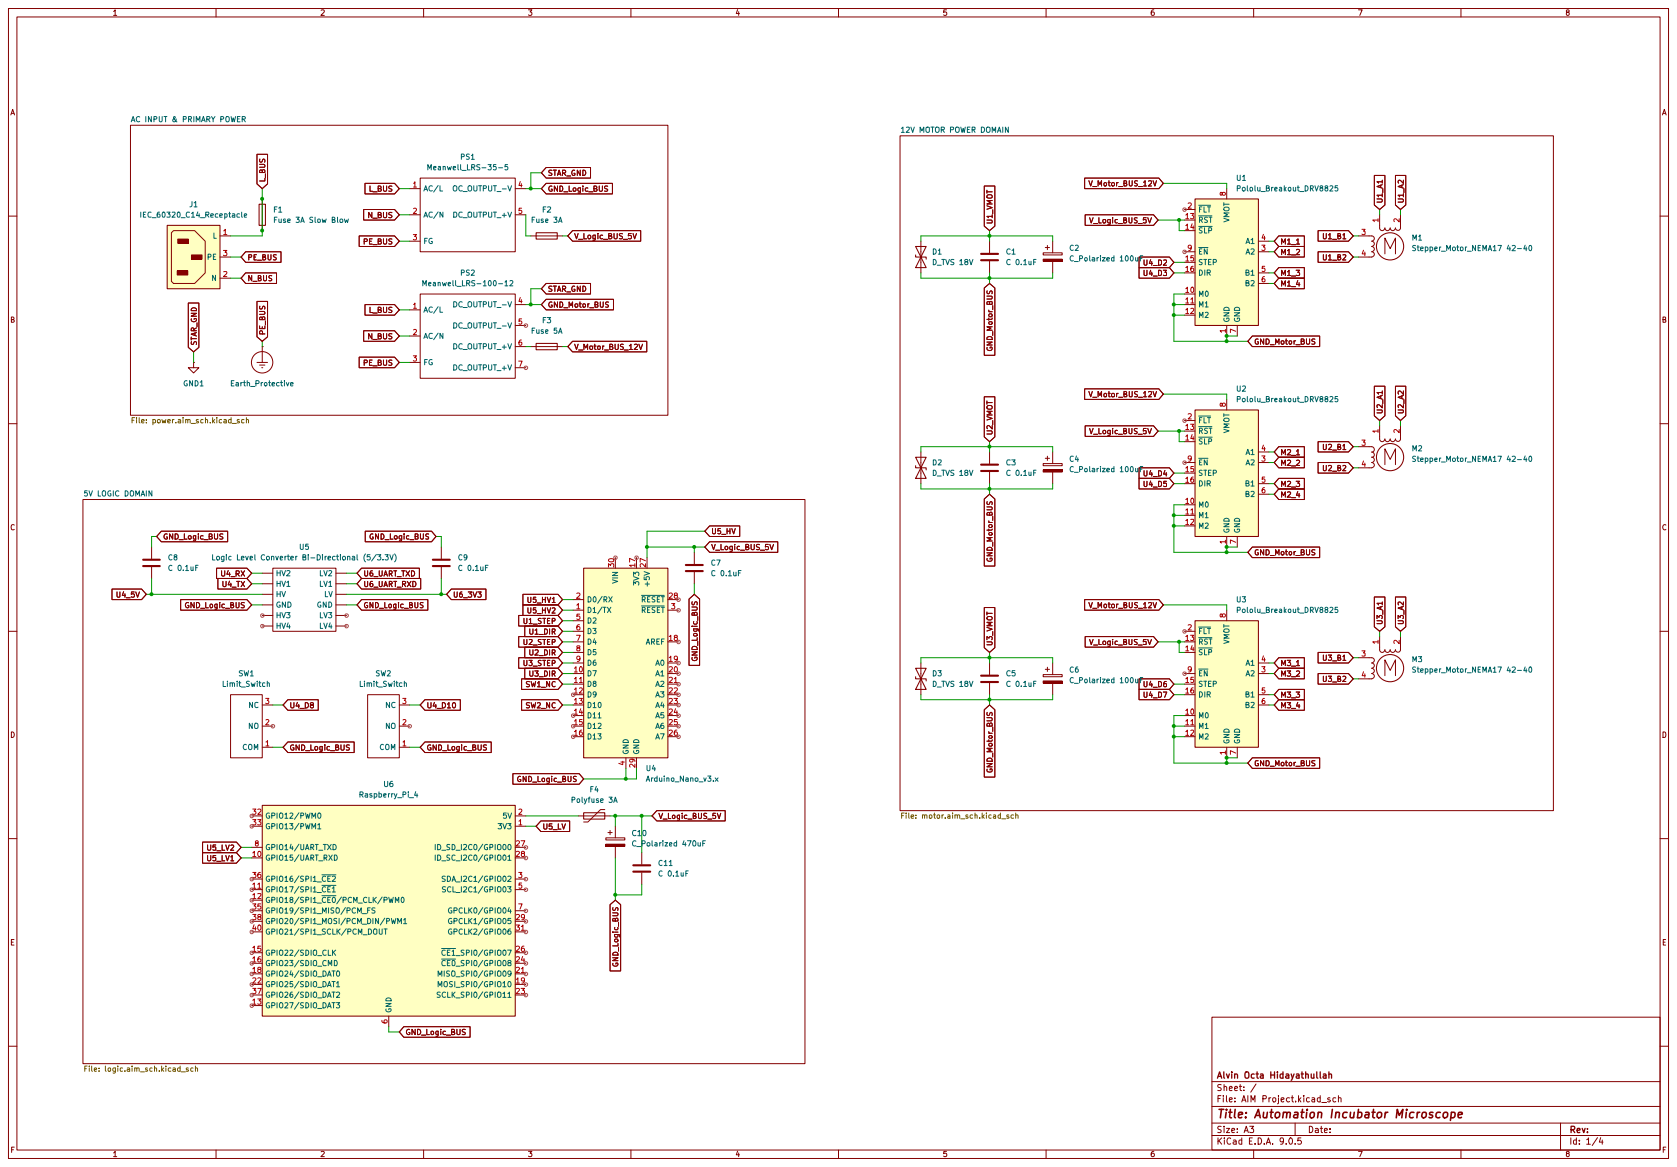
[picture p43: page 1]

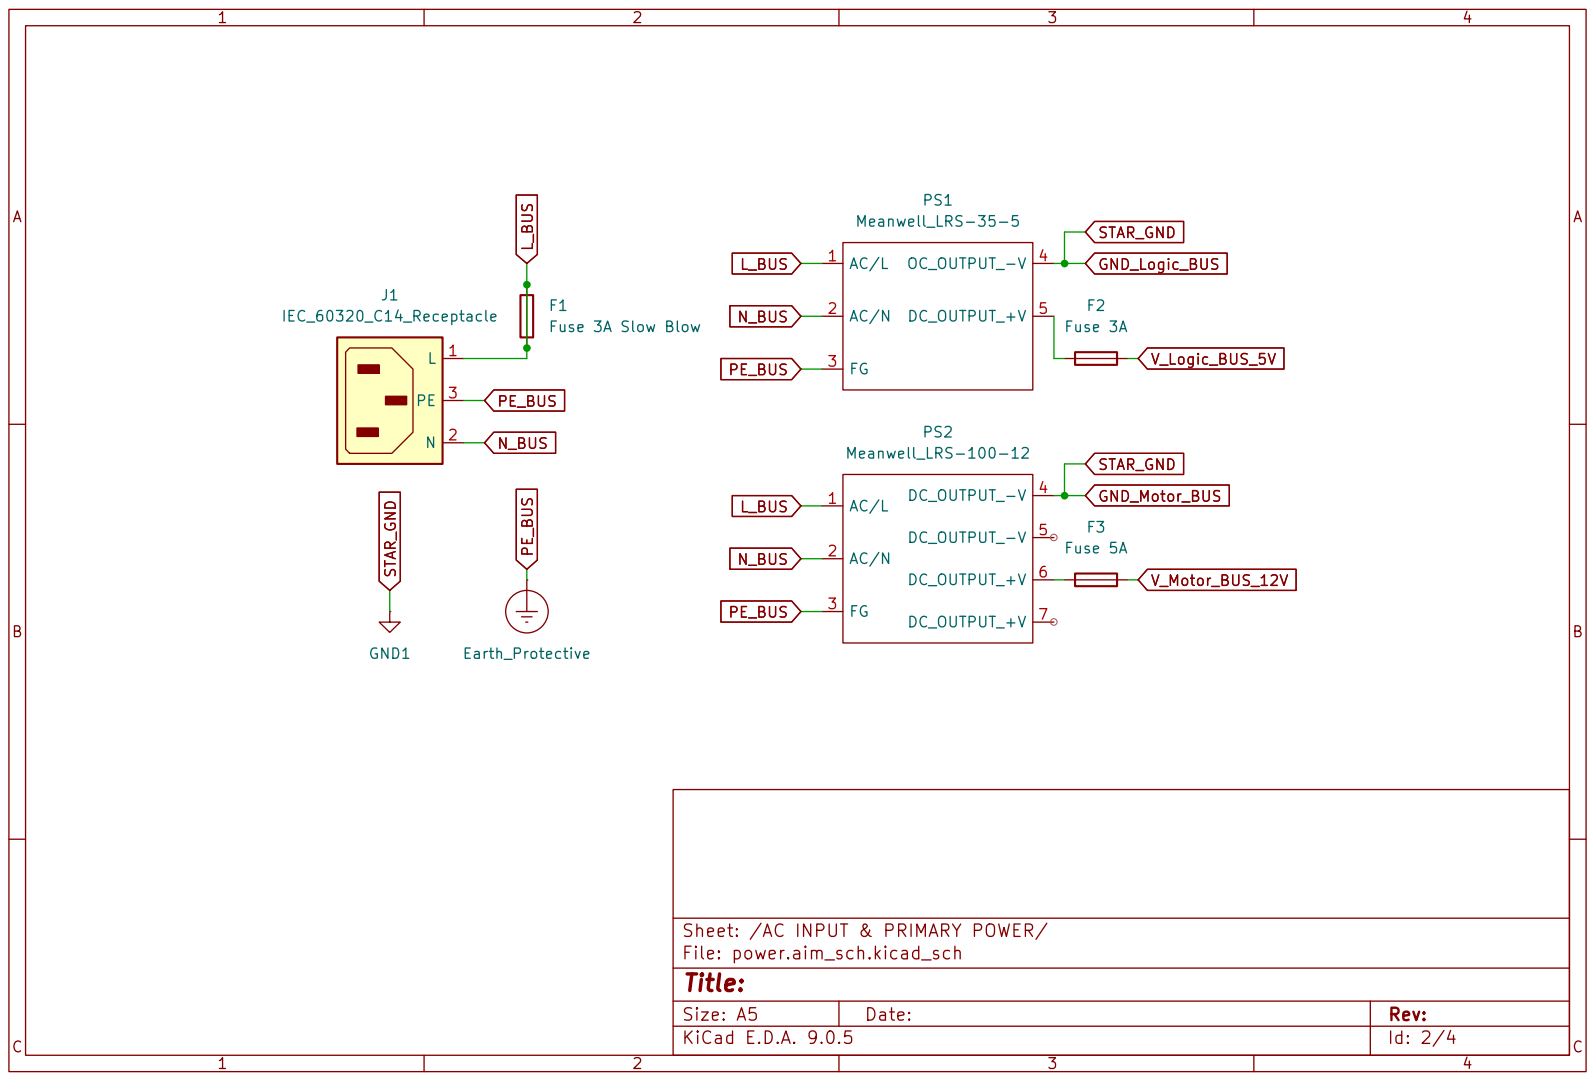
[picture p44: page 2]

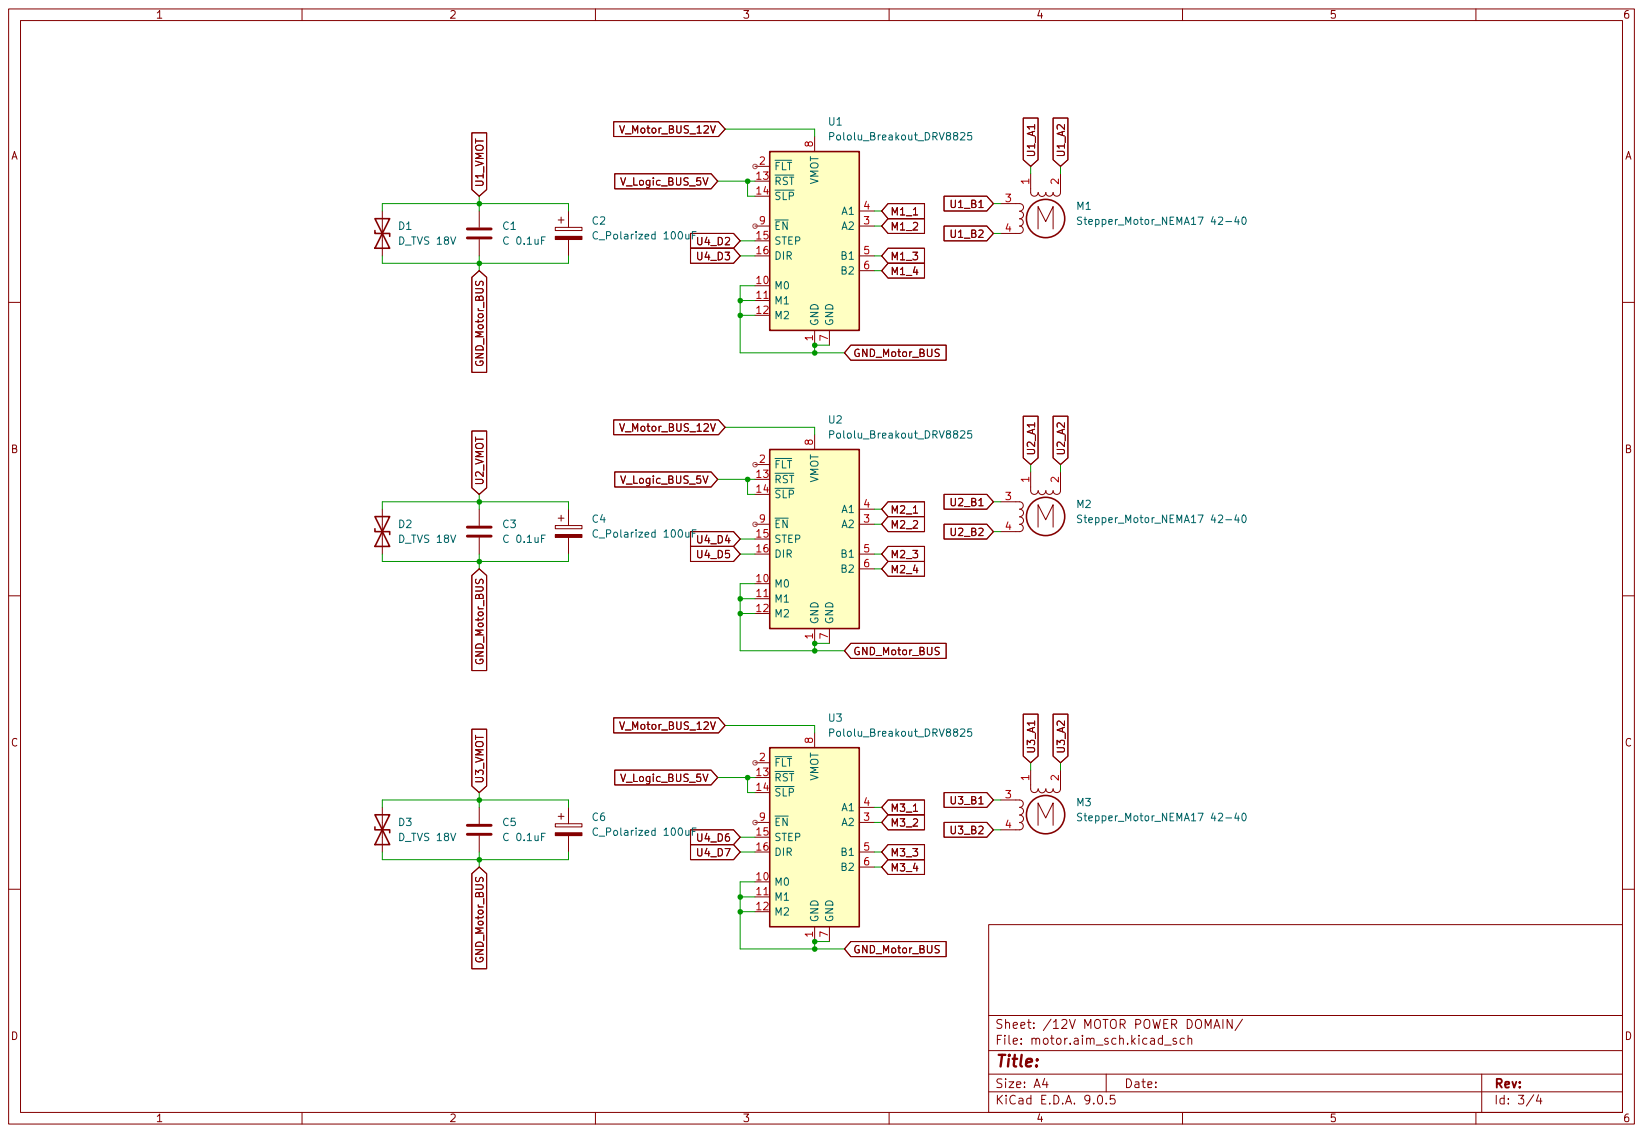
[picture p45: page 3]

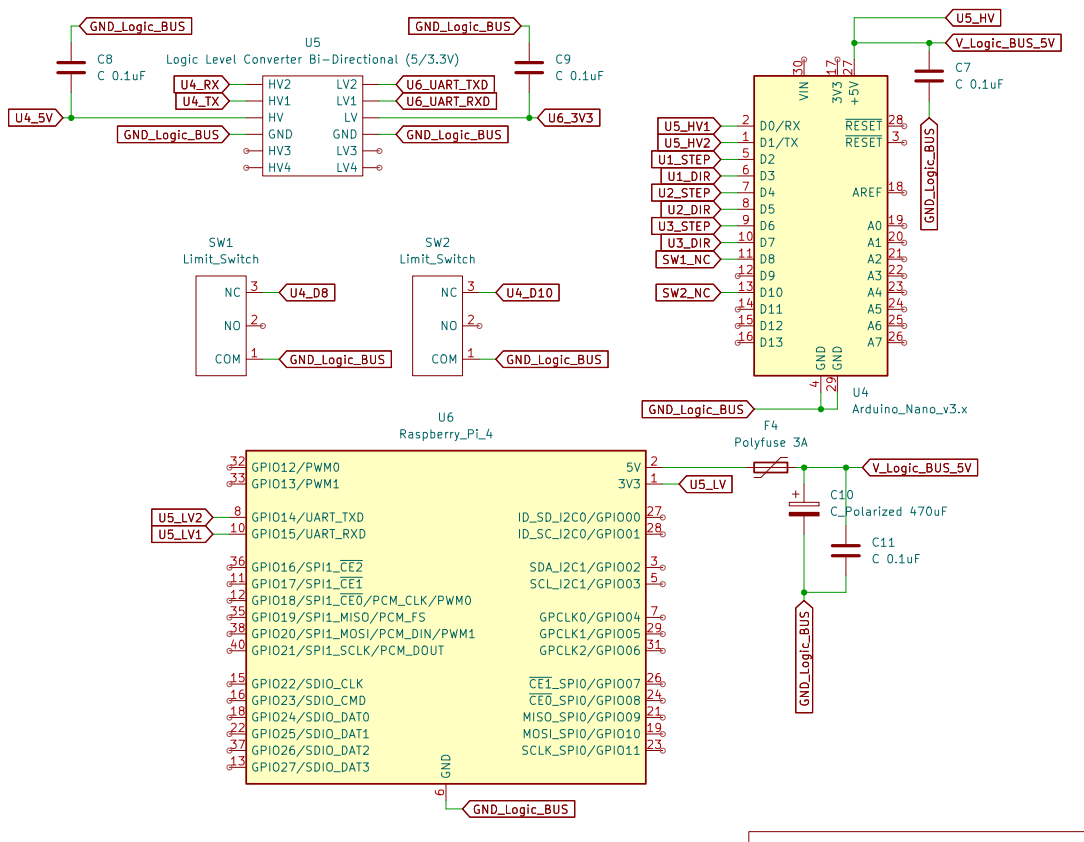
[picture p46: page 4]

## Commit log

2026-04-02 Rename Software Flow.jpg to Software_Flow.jpg
2026-09-12 Restructure stage-plate analysis into mechanical/analysis, add CAD + spheroid data
    - Move FEA result images from mechanical/stage-plate/ to mechanical/analysis/
    to match the naming used elsewhere in the repo.
    - Add full 3D CAD source files (mechanical/3d_design/) previously only kept
    locally.
    - Add spheroid imaging validation data (assets/imaging_results/data_spheroids/)
    captured at three tube lengths (10x and 4x objectives) plus professional
    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
    [10x_objective_lens_finite_160mm.ipt, 12-wellplate.ipt, 24-wellplate.ipt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]
2026-09-12 Add Related Work, Z-Frame Redesign, X/Y-Axis Repeatability, Future Work
    Pulled from the internship progress presentations (not previously in the
    README):
    - Related Work: 5 cited prior projects tackling automated/incubator
    microscopy, plus this project's own angle.
    - Objectives added to Overview.
    - New Mechanical section 4, Z-Frame Redesign (Old vs New): the Z-axis
    frame shortened per supervisor request, validated via FEA before/after
    (displacement 2.01mm -> 0.353mm, ~82% improvement, via added diagonal
    cross-bracing -- stress was never the concern, stiffness was).
    - New Mechanical sections 7-8, X-Axis and Y-Axis Repeatability (phase
    correlation test, 50 cycles each) with charts --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
2026-09-12 Fill in motor bracket displacement comparison (Design Iteration)
    Read the actual max-displacement values off each bracket's FEA screenshot
    (old vs new, X/Y/Z). Only displacement was ever generated for these -- no
    stress/safety-factor contour exists for this analysis, so that's reported
    honestly rather than invented.
    Z bracket redesign (cross-bracing) nearly eliminated its flex (~99.6%
    reduction). Y bracket barely improved (~26%) and is still ~26x more
    flexible than X and ~22,000x more flexible than Z even after redesign --
    this quantifies the mechanical root cause behind the noisier Y-axis
    repeatability result and why it's still top of Future Work.
2026-09-12 Fill in imaging table Notes (microbead + spheroid) and overall Insight
    Reviewed each captured image directly to write per-tube-length notes for
    both objectives (10x/4x) across microbead calibration and spheroid
    confirmation.
    Key finding worth flagging: the nominal 160mm tube length (the objective's
    own spec) was actually the *worst* result for microbeads at 10x -- a
    single unresolvable blur -- while several shorter/longer candidates were
    sharp. Spheroid imaging at 10x held up well across all three tested
    lengths; 4x was inconsistent, likely due to the spheroid's own Z position
    rather than tube length itself.
    Added a synthesized Insight: 10x is the more dependable objective, and
    tube length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
2026-09-12 Add real hardware photos/video, wellplate holder material comparison, Travel(Z), thermal readings, and remaining Insight sections
    - Physical prototype photo and a short motion GIF from an actual test
    recording (first real hardware media in the repo, previously only
    CAD renders and FEA screenshots).
    - Enclosure CAD render added with an explicit "design only, not yet
    fabricated" caption -- doesn't overstate its status.
    - New Wellplate Holder Plate material comparison (PLA-Basic/PLA-CF/
    Al6061), validated against the source presentation as a genuinely
    different part from the existing stage-plate comparison. No safety
    factor computed for it, matching what the source material itself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
2026-09-12 Mark 84.2mm as the final confirmed tube length
    Previously the README tested multiple candidates but never stated which
    one was actually locked in for production use. 84.2mm at 10x was
    confirmed with the supervisor/professor -- its magnification most closely
    matched the professional lab microscope reference.
2026-09-12 Add .gitattributes to fix GitHub language detection
    mechanical/focus_report.html is a 9.6MB auto-generated analysis report
    (embedded plots), which was outweighing the actual Python/Arduino source
    by byte count and making GitHub label the whole repo "HTML". Marked as
    linguist-generated so language stats reflect the real project.
2026-10-15 docs: report X/Y repeatability in pixels instead of µm
    The µm values used the 1.55 µm sensor pixel size without dividing by
    optical magnification, which overstated stage-space distance. Pixels are
    what phase correlation actually measures.
2026-10-15 docs: convert X/Y repeatability to sample-plane µm (0.295 µm/px)
    Full-res 4056x3040 captures, 10x objective at 84.2 mm tube length,
    phase correlation on an unscaled center crop. Adds the derivation and a
    note that the values are below the optical resolution limit.
2026-10-15 feat: add Flask control panel, Arduino firmware and analysis scripts
    - software/backend/app.py + software/frontend/index.html: web panel (stage control,
    live MJPEG view, experiment loop with AT/OK scan handshake, focus sweep at A1)
    - firmware/: Nano V3 firmware over USB serial, and a GPIO UART version (in progress)
    - analysis/: X/Y repeatability (phase correlation) and Z focus validation scripts
    - README: software section matches the code (routes, commands, folder layout, storage)
2026-10-15 docs: credit the earlier prototype and firmware sketch

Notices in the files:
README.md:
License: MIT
